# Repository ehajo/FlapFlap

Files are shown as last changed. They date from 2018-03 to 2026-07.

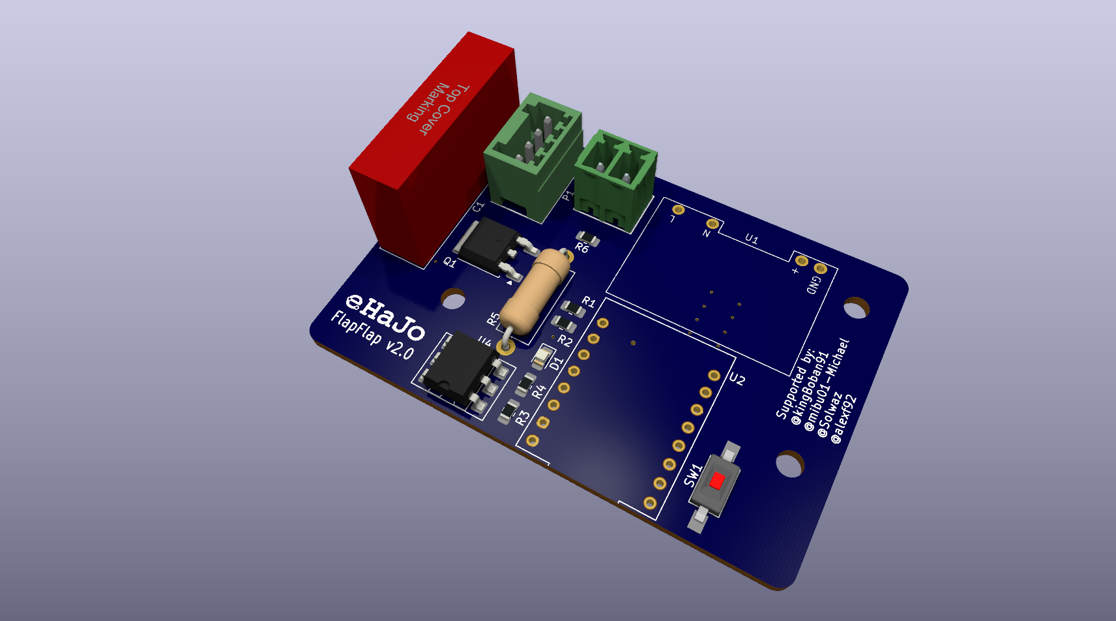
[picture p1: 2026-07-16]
Platine/KiCad/flapflap/flapflap.png

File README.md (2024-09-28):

# FlapFlap

Die Daten zum Fallblattanzeigen-Projekt, das wir auf Youtube und im Twitch-Livestream bearbeiten.

Unsere Streams findest du auf https://www.twitch.tv/ehajo

Die neue Version bekommt eine komplett neue Hardware. Es wird sowohl die komplette Ansteuerung als auch die Absolutpositionsabfrage getauscht!

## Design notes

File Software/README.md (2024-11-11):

# FlapFlap Sub-Clock & Uhr Software

Willkommen zu der FlapFlap-Software! Dieses Projekt umfasst zwei Hauptfunktionen: eine **normale Uhr** und eine **Sub-Clock**. Die Software läuft auf einem **Raspberry Pi Pico W** und verwendet den **TLV493D Magnetfeldsensor**, um die Zeit in verschiedenen Formaten zu messen und darzustellen. Sie kann für die Anzeige von Sekunden, Minuten und Stunden konfiguriert werden. Diese README erklärt die Funktionsweise, wie du die Software einrichtest und wie du die Konfiguration anpassen kannst.

## Funktionen

Die FlapFlap Software bietet eine Vielzahl von Funktionen, die auf den folgenden beiden Hauptvarianten basieren:

### 1. Normale Uhr

Die normale Uhr liest den Magnetfeldsensor aus, um den Rotationswinkel der Uhr zu berechnen. Der Mikrocontroller zeigt basierend auf diesem Winkel und der konfigurierten Logik die Zeit in **Sekunden**, **Minuten** oder **Stunden** an. Die aktuelle Uhrzeit wird per NTP-Protokoll bei funktionierendem WLAN geladen, ansonsten über einen RTC-Chip, der per I²C angeschlossen ist.

- **Sekunden**: Zeigt die Sekunden an.
- **Minuten**: Zeigt die Minuten an.
- **Stunden**: Zeigt die Stunden an.

### 2. Sub-Clock

Die Sub-Clock ist eine alternative Anzeige, die speziell für eine reduzierte Zeitdarstellung gedacht ist. Sie empfängt dieselben Werte über den UART-Datenstrom, aber die Interpretation der Daten erfolgt je nach den spezifischen Anforderungen des Projekts (z. B. eine präzisere, abgestufte Anzeige).

## Systemanforderungen

- **Hardware**:
  - Raspberry Pi Pico W oder vergleichbare Mikrocontroller mit CircuitPython-Unterstützung.
  - TLV493D Magnetfeldsensor (I2C-Schnittstelle).
  - Eine UART-Schnittstelle für die serielle Kommunikation.
- **Software**:
  - CircuitPython für die Ausführung der Software.
  - `adafruit_tlv493d`-Bibliothek für den Magnetfeldsensor.

## Installation

### Abhängigkeiten

Für die Installation sind folgende Bibliotheken erforderlich:

- **Adafruit TLV493D**: Diese Bibliothek ist notwendig, um den Magnetfeldsensor über die I2C-Schnittstelle anzusprechen.
  
Installiere die Bibliothek über den CircuitPython-Installer oder lade sie manuell herunter.

### Code Setup

1. **Code auf den Raspberry Pi Pico W hochladen**:
   Lade die Python-Dateien auf den Raspberry Pi Pico W hoch und speichere sie im Hauptverzeichnis.
   
2. **I2C und UART konfigurieren**:
   Stelle sicher, dass die I2C- und UART-Verbindungen für deinen Raspberry Pi Pico W richtig eingerichtet sind.

3. **Konfigurationsdatei (`config.json`) erstellen**:
   Stelle sicher, dass eine gültige `config.json`-Datei im Hauptverzeichnis des Dateisystems des Raspberry Pi Pico W vorhanden ist. Diese Datei enthält alle Einstellungen für die Uhr und Sub-Clock.

## config.json

Die `config.json`-Datei speichert die Konfiguration für die Uhr, einschließlich des kalibrierten Nullpunkts und des Typs der angezeigten Zeit (Sekunden, Minuten, Stunden oder eine benutzerdefinierte Sub-Clock-Logik).

### Beispiel `config.json`:

```json
{
  "calibrated_zero_angle": 91.4311,
  "type": "Sekunden"
}
```

### Konfigurationsfelder:

- **`calibrated_zero_angle`**:
  - Dies ist der kalibrierte Nullpunktwinkel in Grad. Er gibt den Referenzwinkel an, ab dem die Uhr arbeitet. Dieser Wert wird durch die Kalibrierung des Magnetfeldsensors bestimmt.
  - **Wertbereich**: Ein numerischer Wert zwischen 0 und 360.
  - **Beispiel**: `91.4311`

- **`type`**:
  - Dieser Parameter bestimmt, welche Zeit angezeigt wird und wie der empfangene Datenstrom über UART interpretiert wird. Es gibt mehrere Optionen, die du je nach deinen Anforderungen wählen kannst.
  - **Mögliche Werte für `type`**:
    - `"Sekunden"`: Die Uhr zeigt die Sekunden an. Der empfangene Datenstrom steuert die Sekunden.
    - `"Minuten"`: Die Uhr zeigt die Minuten an. Der empfangene Datenstrom steuert die Minuten.
    - `"Stunden"`: Die Uhr zeigt die Stunden an. Der empfangene Datenstrom steuert die Stunden.
    - `"nix62"`: Diese Einstellung zeigt immer die Stufe 31 an, bedeutet bei einer Minutenanzeige das Leerfeld.
    - `"nix40"`: Diese Einstellung zeigt immer die Stufe 26 an, bedeutet bei einer Stundenanzeige das Leerfeld.
    - **Beispiel für Konfigurationen**:
      - **Sekundenanzeige**:
        ```json
        {
          "calibrated_zero_angle": 91.4311,
          "type": "Sekunden"
        }
        ```
      - **Minutenanzeige**:
        ```json
        {
          "calibrated_zero_angle": 120.0,
          "type": "Minuten"
        }
        ```
      - **Stundenanzeige**:
        ```json
        {
          "calibrated_zero_angle": 180.5,
          "type": "Stunden"
        }
        ```
      - **Sub-Clock-Variante (nix62)**:
        ```json
        {
          "calibrated_zero_angle": 91.4311,
          "type": "nix62"
        }
        ```
      - **Sub-Clock-Variante (nix40)**:
        ```json
        {
          "calibrated_zero_angle": 91.4311,
          "type": "nix40"
        }
        ```

## wlan.json

Die `wlan.json`-Datei speichert die Konfiguration für die WLAN-Einstellungen. Passe diese bitte an deine Zugangsdaten zu deinem Heimnetz an.
```json
{
    "wifi_ssid": "your-ssid",
    "wifi_password": "1234567890"
}
```

## Kalibrierung

Die Kalibrierung des Magnetfeldsensors erfolgt durch den Benutzer, um den Nullpunktwinkel festzulegen. Wenn du den Button (GPIO22) drückst, wird der Sensor neu kalibriert, und der aktuelle Winkel wird als Nullpunkt gespeichert. Der Nullpunkt wird dann in der `config.json`-Datei gespeichert, sodass er bei jedem Neustart des Geräts wieder verwendet werden kann.

### Kalibrierungsschritte:

1. Drücke den Kalibrierungs-Button (GPIO22).
2. Die Software misst das Magnetfeld und berechnet den Nullpunktwinkel.
3. Der neue Nullpunkt wird in der `config.json` gespeichert.

## UART-Datenstrom

Die Software empfängt über die serielle Schnittstelle UART bis zu drei Bytes:

1. **Sekunden (Typ `"Sekunden"`)**: Das erste Byte gibt die Zielstufe für die Sekunden an (Wertbereich: 0-62).
2. **Minuten (Typ `"Minuten"`)**: Das zweite Byte gibt die Zielstufe für die Minuten an (Wertbereich: 0-62).
3. **Stunden (Typ `"Stunden"`)**: Das dritte Byte gibt die Zielstufe für die Stunden an (Wertbereich: 0-40).

Die empfangenen Bytes werden verwendet, um die `step_target`-Variable zu setzen. Wenn die aktuelle Stufe der Zielstufe entspricht, wird die Anzeige entsprechend aktualisiert.

### Beispiel für einen gültigen Datenstrom:
- Wenn der `type` auf `"Sekunden"` gesetzt ist, wird das erste Byte die Sekunden definieren.
- Bei `"Minuten"` und `"Stunden"` werden die entsprechenden Bytes verwendet.

## Häufige Fehlerbehebung

- **Konfigurationsdatei fehlt**: Wenn die `config.json`-Datei nicht gefunden wird, wird ein Standardwert verwendet. Stelle sicher, dass die Datei korrekt erstellt und im richtigen Verzeichnis abgelegt wurde.
- **Datenübertragung funktioniert nicht**: Überprüfe die UART-Verbindung und stelle sicher, dass der Mikrocontroller korrekt mit dem Sender kommuniziert.
- **Magnetfeldsensor kalibrieren**: Falls die Kalibrierung fehlschlägt oder der Nullpunkt fehlerhaft ist, stelle sicher, dass der Magnetfeldsensor richtig angeschlossen und korrekt kalibriert wurde.

## Lizenz

Dieses Projekt ist unter der [MIT-Lizenz](LICENSE) lizenziert.

---

Für weitere Informationen oder Fragen besuche unsere Website: [eHaJo.de](https://www.eHaJo.de) oder schließe dich unserem [Twitch-Livestream](https://www.twitch.tv/eHaJo) an!

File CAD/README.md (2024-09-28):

# CAD-Daten FlapFlap

Die Daten wurden mit AlibreDesign erstellt. Zusätzlich findest du hier Step-Daten zum Import in andere CAD-Programme!

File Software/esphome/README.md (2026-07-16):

# FlapFlap

ESPHome-Projekt für eine historische Fallblattanzeige mit Magnetfeldsensor-Rückmeldung und pulseweiser Motoransteuerung.

## Ziel des Projekts

Dieses Projekt steuert eine Fallblattanzeige mit einem ESP32-C3 Super Mini.  
Die Blattposition wird über einen **TLV493D 3D-Magnetfeldsensor** erfasst.  
Der Motor wird über einen **MOC3043** angesteuert.  
Die Anzeige bewegt sich **nur vorwärts**.  
Ziel ist eine robuste Anfahrt eines gewünschten Blatts mit Rückmeldung über den Sensor.

## Hardware

### Controller
- ESP32-C3 Super Mini

### Sensor
- Infineon TLV493D-A1B6
- I2C-Adresse: `0x5E`

### Aktorik
- MOC3043 zur Ansteuerung des Motors

### Bedienelement
- Taster gegen GND, interner Pull-up im ESP32-C3

## Verbindliche Pinbelegung

- **TLV493D SDA** → `GPIO0`
- **TLV493D SCL** → `GPIO1`
- **Taster** → `GPIO3` gegen GND
- **MOC3043 Eingang** → `GPIO10`

## Wichtige Hardware-Hinweise

### Pull-ups
Für I2C sind externe Pull-ups erforderlich:
- SDA → 3V3 über **4,7 kΩ**
- SCL → 3V3 über **4,7 kΩ**

Keine 1-kΩ-Pull-ups verwenden.

### Versorgung
- TLV493D nur mit **3,3 V**
- keine 5-V-Pegel an ESP32-C3-GPIOs

### ESP32-C3 Pin-Einschränkungen
Diese Pins möglichst nicht für das Projekt verwenden:
- `GPIO2`, `GPIO8`, `GPIO9` → Strapping-/Bootstrap-Pins
- `GPIO4` bis `GPIO7` → JTAG-belegt bzw. vermeiden
- `GPIO18`, `GPIO19` → USB Serial/JTAG
- `GPIO20`, `GPIO21` → nach Möglichkeit frei lassen

## Software-Stack

- **ESPHome 2026.3.2**
- Arduino-Framework auf ESP32-C3
- lokaler External Component für den TLV493D und die Regelung

## Repo-Struktur

```text
.
├── flapflap.yaml
├── my_components/
│   └── tlv493d_test/
│       ├── __init__.py
│       ├── tlv493d_test.h
│       └── tlv493d_test.cpp
└── README.md
```

## Aktueller Funktionsumfang

Der aktuelle Stand kann:

- TLV493D per I2C ansprechen
- Magnetfeldwerte X/Y/Z lesen
- Winkel aus X/Y berechnen
- Winkel glätten und stabilisieren
- aktuelle Blattnummer aus Winkel und Nullwinkel bestimmen
- auf ein beliebiges Blatt kalibrieren
- Motor pulseweise ansteuern
- ein Zielblatt anfahren
- Timeout und fehlenden Fortschritt erkennen

## Grundannahmen der Regelung

- Die Anzeige bewegt sich nur **vorwärts**
- Die typische Drehgeschwindigkeit liegt ungefähr bei **5 Blättern pro Sekunde**
- Die Blattnummer wird aus dem Sensorwinkel mit Hysterese bestimmt
- Die Sensorlogik muss im Stillstand stabil sein, darf aber während der Bewegung nicht zu träge werden

## Wichtige ESPHome-Parameter

Typische relevante Parameter im Component:
- `pages`
- `zero_angle`
- `calibration_leaf`
- `target_leaf`
- `sensor_samples`
- `motor_pulse_ms`
- `motor_settle_ms`
- `move_timeout_ms`
- `max_pulses_per_move`
- `unchanged_limit`

## Build

Projekt kompilieren:

```bash
esphome compile flapflap.yaml
```

Projekt flashen / ausführen:

```bash
esphome run flapflap.yaml
```

Logs ansehen:

```bash
esphome logs flapflap.yaml
```

## Typischer Testablauf

1. Hardware prüfen
2. I2C-Scan prüfen, Sensor muss auf `0x5E` erscheinen
3. Sensorwerte X/Y/Z und Winkel prüfen
4. Kalibrierblatt setzen
5. `Hier kalibrieren` auslösen
6. prüfen, ob `Aktuelles Blatt` stabil ist
7. `Zielblatt` setzen
8. `Zu Zielblatt fahren` testen
9. bei Problemen Logs auf Blattwechsel, Pulse und Status prüfen

## Bekannte Besonderheiten

- Der TLV493D kann nach problematischen I2C-Transaktionen in einem ungünstigen Zustand hängen. In solchen Fällen hilft oft ein vollständiger Power-Cycle.
- Blattgrenzen sind empfindlich; deshalb sind Mittelung, Vektorfilterung und Hysterese wichtig.
- Übergänge um 0°/360° müssen besonders robust behandelt werden.

## Erwartungen an Änderungen

Bitte Änderungen **minimal und gezielt** halten.

### Nicht ohne Not ändern
- Pinbelegung
- I2C-Adresse
- Kalibrierlogik-Grundprinzip
- Blattberechnung nur vorwärts
- ESPHome-Version-Kompatibilität zu 2026.3.2

### Bevorzugte Arbeitsweise
- kleine, nachvollziehbare Änderungen
- bestehende Logik erhalten
- zuerst Buildfehler beheben
- danach Kompilierung erneut prüfen
- keine unnötigen Refactorings

## Definition of Done

Eine Änderung ist fertig, wenn:

1. `esphome compile flapflap.yaml` erfolgreich läuft
2. keine bestehenden Funktionen unbeabsichtigt entfernt wurden
3. Sensorwerte weiterhin plausibel sind
4. Kalibrierung weiterhin funktioniert
5. die Blattberechnung stabil bleibt
6. Motorsteuerung nicht dauerhaft hängen bleibt
7. Logs weiterhin hilfreich und präzise sind

## Hinweise für Coding Agents / Codex

Wenn du als Agent in diesem Repo arbeitest:

- lies zuerst diese Datei vollständig
- ändere nur die minimal nötigen Dateien
- erkläre kurz die Ursache eines Problems
- führe nach Änderungen `esphome compile flapflap.yaml` aus
- behebe verbleibende Buildfehler
- erhalte bestehende Hardware-Pins und Projektziele
- vermeide große Umbauten ohne ausdrückliche Aufforderung
- bevorzuge robuste, konservative Änderungen gegenüber kreativen Refactorings

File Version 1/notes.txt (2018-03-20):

52,08uS pro Bit @ 19k2

T3.5 = 156,25 uS @ 19K2

@8MHz 156,2uS ist x Clk

156,2 uS / 125ns = 156,2 / 125 * 1000

= 1249,6 Clocks

-> 16 Bit Timer mit F_CPU nötig, oder 8 Bit Timer mit F_CPU /4 bis F_CPU / 8

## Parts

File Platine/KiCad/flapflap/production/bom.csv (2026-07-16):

Designator | Footprint | Quantity | Value | LCSC Part #
C1 | C_Wurth_WCAP-FTBP-P22.5L26W7H16.5 | 1 | 1.5 uF
C2 | 0805 | 1 | 100n
D1 | 0805 | 1 | LED
P1 | 691382000004 | 1 | 691382010004
P2 | 691321300002 | 1 | 691322110002
Q1 | TO-252-2 | 1 | T835-600B-TR
R1, R2 | 0805 | 2 | 4k7
R3, R4 | 0805 | 2 | 470R
R5 | R_Axial_DIN0414_L11.9mm_D4.5mm_P15.24mm_Horizontal | 1 | 3k3/2W
R6 | 0805 | 1 | 1k
SW1 | SW_SPST_FSMSM | 1 | SW_Push
U1 | ACDC-230 | 1 | youmile_230acdc
U2 | MODULE_ESP32-C3_SUPERMINI_TH | 1 | ESP32-C3_SUPERMINI_TH
U3 | SOT-23-6 | 1 | TLV493D
U4 | DIP-6_W7.62mm_SMDSocket_SmallPads | 1 | MOC3043M

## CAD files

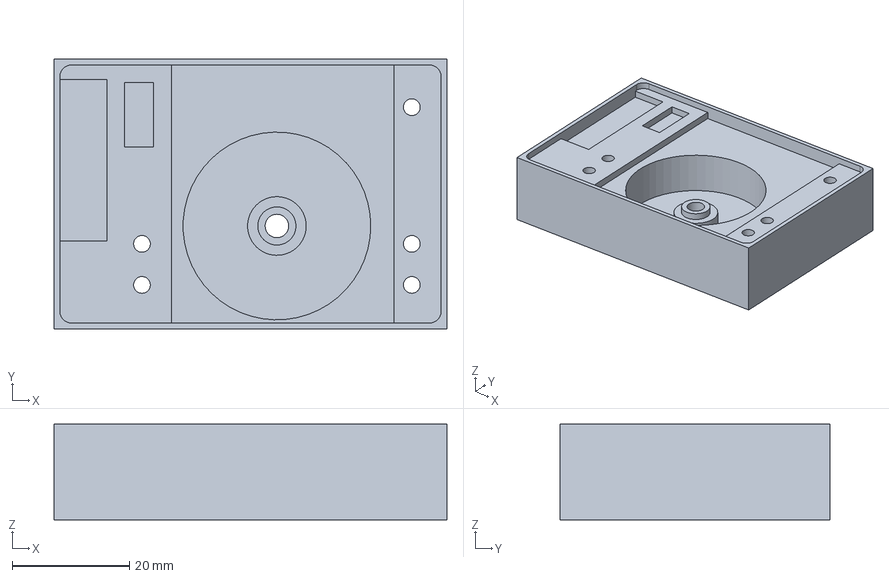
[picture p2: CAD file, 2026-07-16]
CAD/gehäuse_neu.stp
67.0 x 46.0 x 16.3 mm

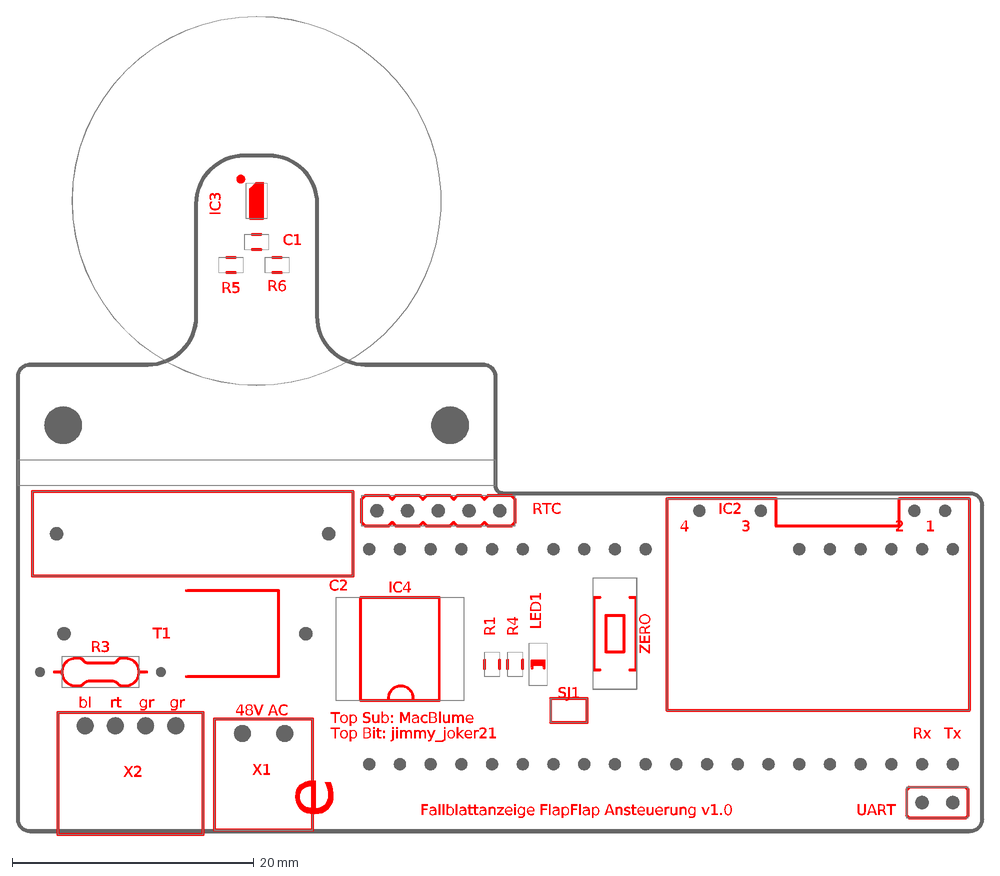
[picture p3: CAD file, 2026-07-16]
Platine/flapflap_rPi_picoW.dxf
Rx
Tx
Top Bit: jimmy_joker21
Top Sub: MacBlume
e
Fallblattanzeige FlapFlap Ansteuerung v1.0
gr
rt
bl
48V AC
R6
R5
SJ1
C2
ZERO
UART
R4
LED1
RTC
X2
R3
T1
R1
IC4
C1
IC3
IC2
4
3
2
1
X1

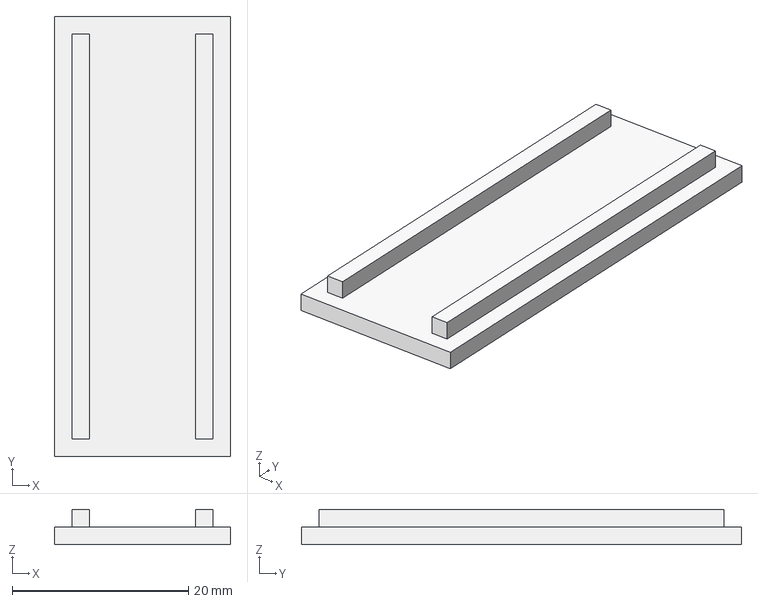
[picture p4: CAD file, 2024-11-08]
CAD/stromversorgung_deckel.stp
20.0 x 50.0 x 4.00 mm

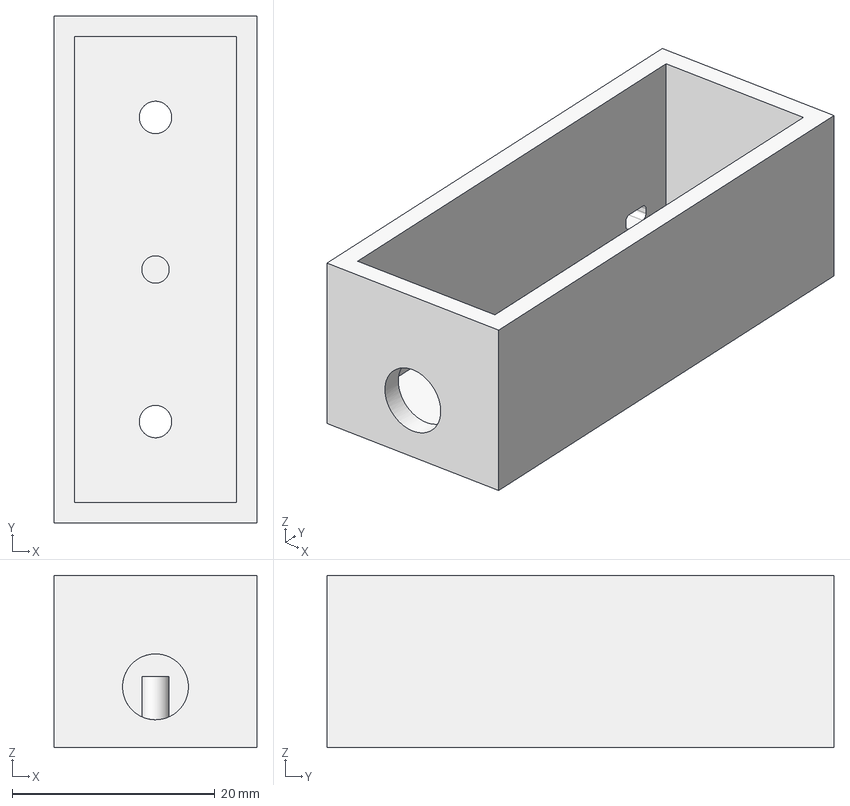
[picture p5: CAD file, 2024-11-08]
CAD/stromversorgung_unterteil.stp
20.0 x 50.0 x 17.0 mm

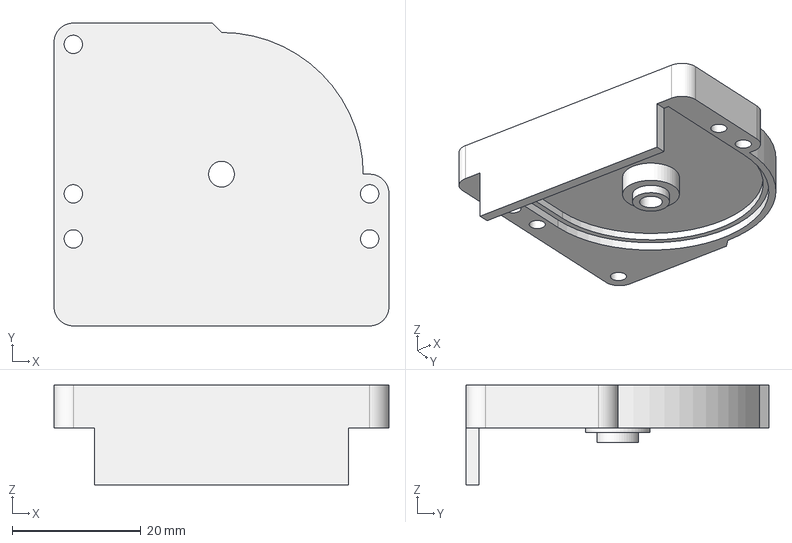
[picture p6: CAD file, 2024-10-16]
CAD/inkrementalgeber_unterseite.stp
52.0 x 47.0 x 15.5 mm

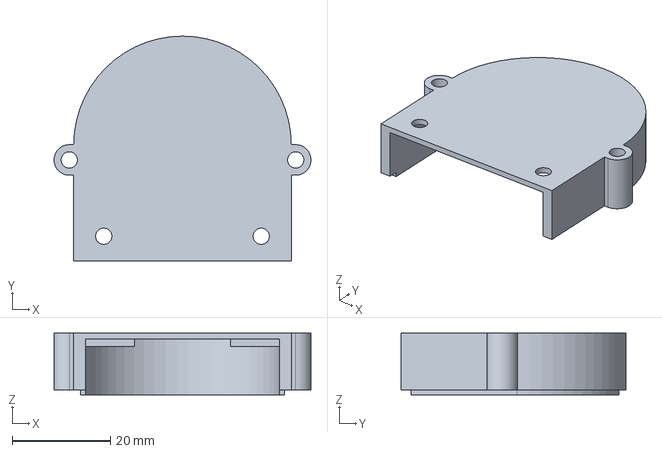
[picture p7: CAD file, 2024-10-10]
CAD/inkrementalgeber_oberseite.stp
52.2 x 45.7 x 12.5 mm

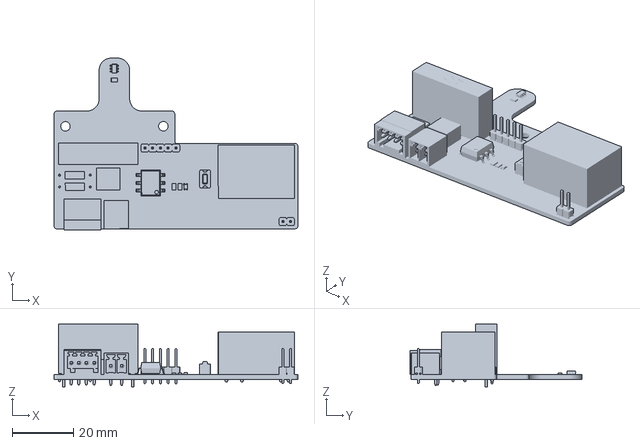
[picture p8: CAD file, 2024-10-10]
CAD/flapflap_rpi_picow.3mf
79.8 x 56.2 x 20.5 mm

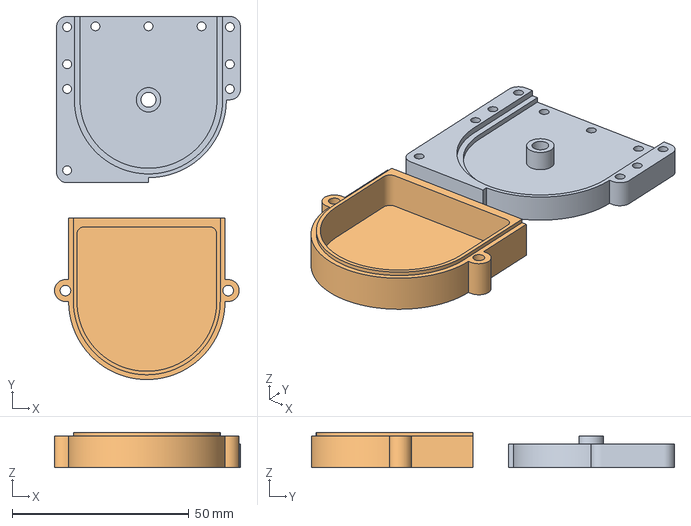
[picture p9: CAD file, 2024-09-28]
CAD/inkrementalgeber_gehaeuse.3mf
52.6 x 102.6 x 10.0 mm
inkrementalgeber_unterseite.stp
inkrementalgeber_oberseite.stp

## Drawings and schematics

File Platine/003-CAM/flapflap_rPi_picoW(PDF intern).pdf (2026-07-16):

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

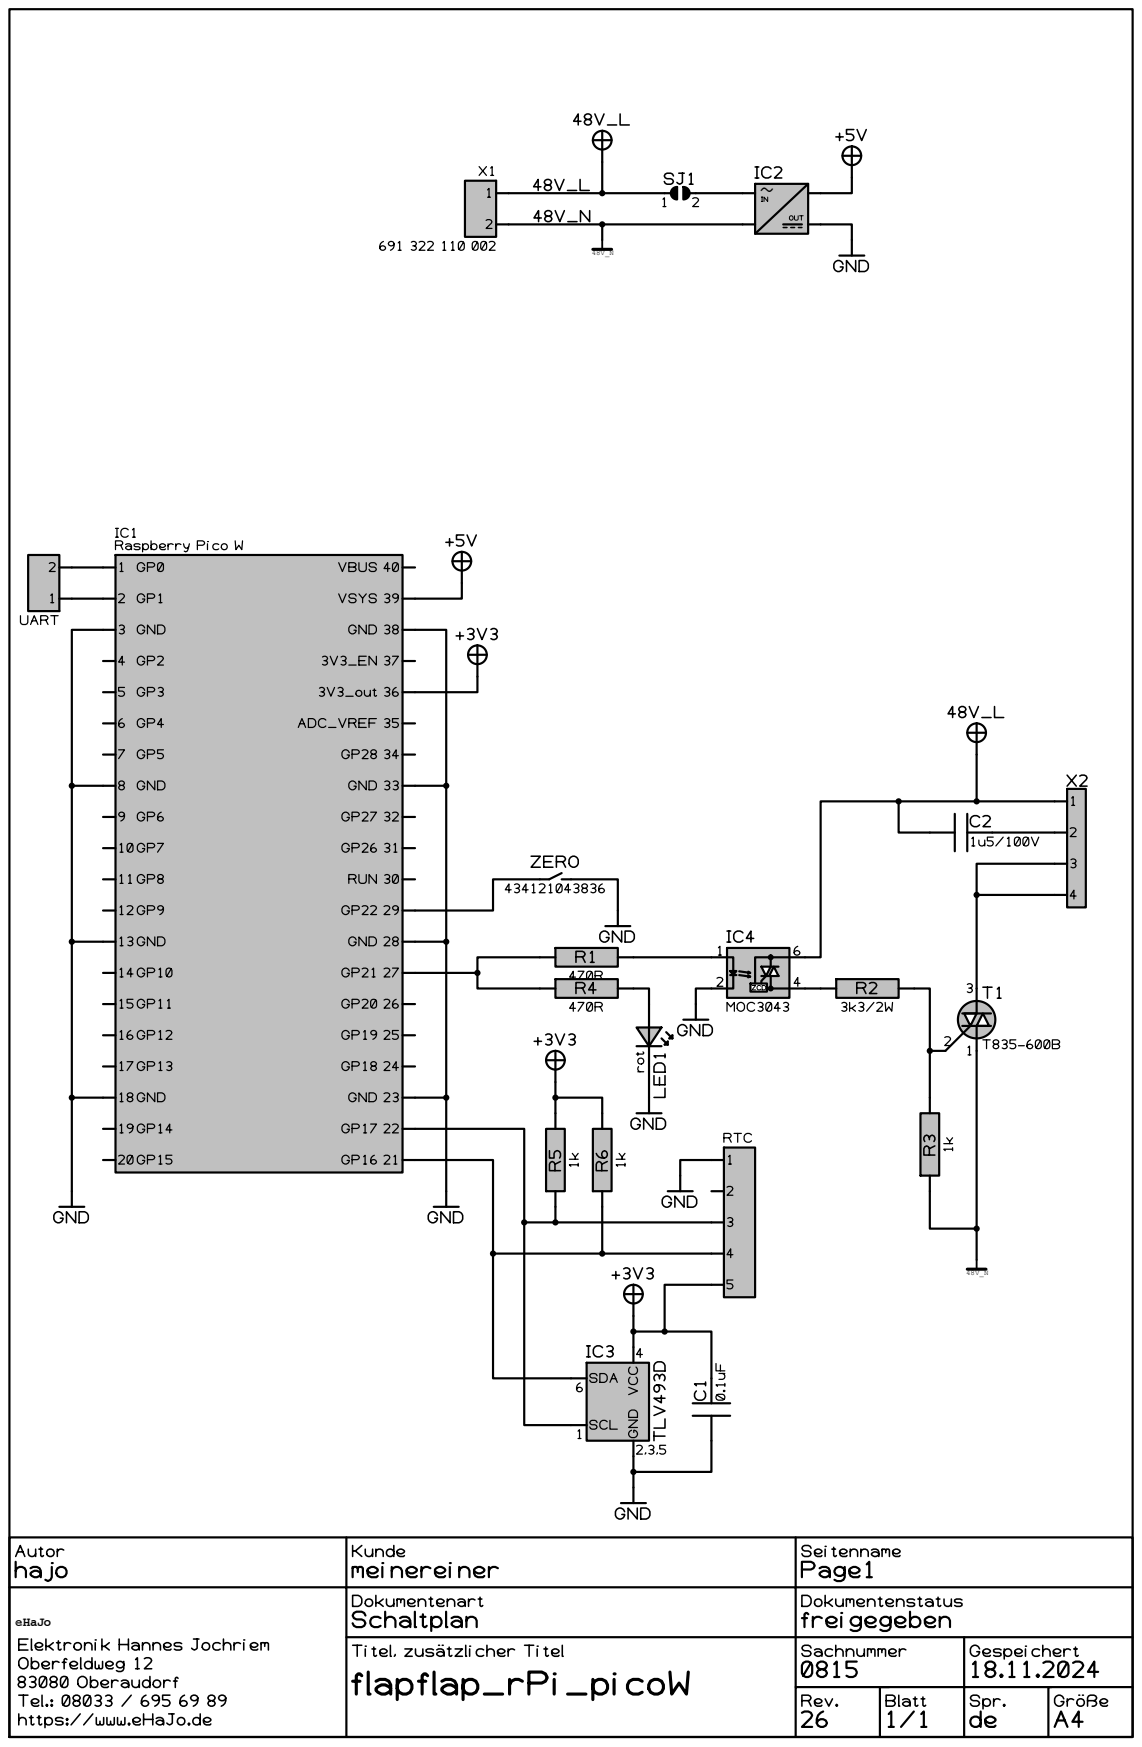
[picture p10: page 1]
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

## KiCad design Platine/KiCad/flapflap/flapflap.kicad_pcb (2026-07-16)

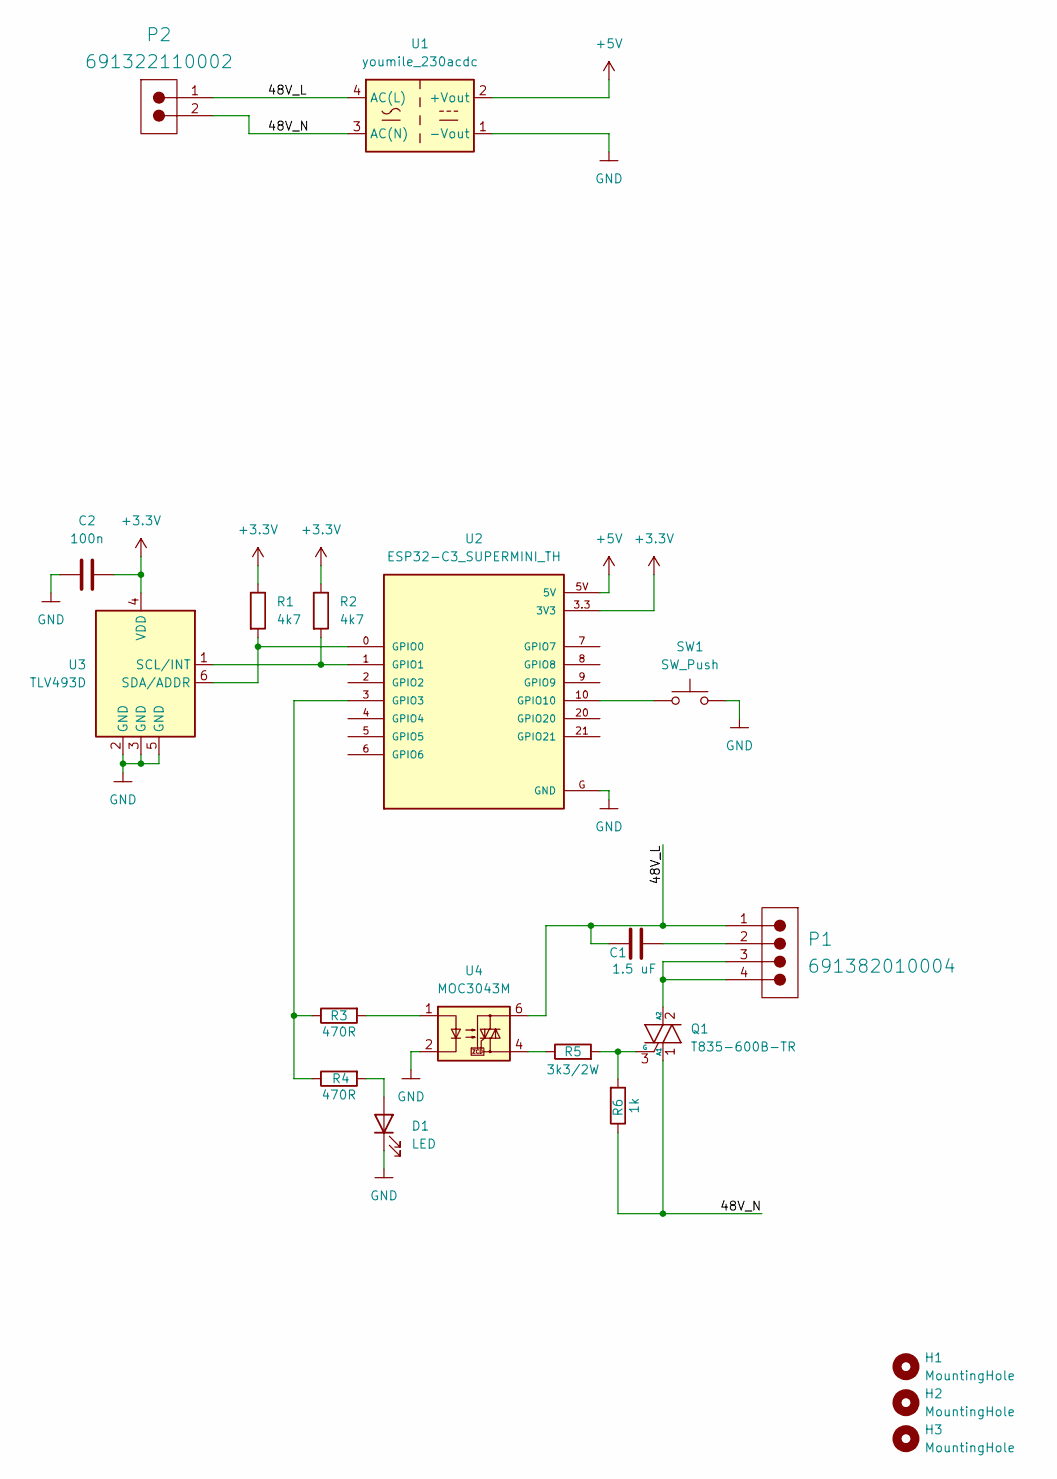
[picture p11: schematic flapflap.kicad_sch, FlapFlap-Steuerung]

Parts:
C1: 1.5 uF; C_Wurth_WCAP-FTBP-P22.5L26W7H16.5; Voltage 250; Part Number 890273326007CS
C2: 100n; C_0805_2012Metric_Pad1.18x1.45mm_HandSolder
D1: LED; LED_0805_2012Metric_Pad1.15x1.40mm_HandSolder
H1, H2, H3: MountingHole; MountingHole_3.2mm_M3
P1: 691382010004; 691382000004; Working Voltage 300V; Manufacturer Part Number 691382000004
P2: 691322110002; 691321300002; Working Voltage 300V; Manufacturer Part Number 691321300002
Q1: T835-600B-TR; TO-252-2
R1, R2: 4k7; R_0805_2012Metric_Pad1.20x1.40mm_HandSolder
R3, R4: 470R; R_0805_2012Metric_Pad1.20x1.40mm_HandSolder
R5: 3k3/2W; R_Axial_DIN0414_L11.9mm_D4.5mm_P15.24mm_Horizontal
R6: 1k; R_0805_2012Metric_Pad1.20x1.40mm_HandSolder
SW1: SW_Push; SW_SPST_FSMSM
U1: youmile_230acdc; ACDC-230
U2: ESP32-C3_SUPERMINI_TH; MODULE_ESP32-C3_SUPERMINI_TH
U3: TLV493D; SOT-23-6
U4: MOC3043M; DIP-6_W7.62mm_SMDSocket_SmallPads

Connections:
+3.3V: C2.2, R1.1, R2.1, U2.3.3 (3V3), U3.4 (VDD)
+5V: U1.2 (+Vout), U2.5V
/48V_L: C1.1, P1.1, P2.1, U1.4 (AC(L)), U4.6
/48V_N: P2.2, Q1.1 (A1), R6.1, U1.3 (AC(N))
GND: C2.1, D1.1 (K), SW1.1, U1.1 (-Vout), U2.G (GND), U3.2 (GND), U3.3 (GND), U3.5 (GND), U4.2
unnamed: C1.2, P1.2
unnamed: D1.2 (A), R4.2
unnamed: P1.3, P1.4, Q1.2 (A2)
unnamed: Q1.3 (G), R5.2, R6.2
unnamed: R3.2, U4.1
unnamed: R5.1, U4.4
unnamed: R1.2, U2.0 (GPIO0), U3.6 (SDA/ADDR)
unnamed: R2.2, U2.1 (GPIO1), U3.1 (SCL/INT)
unnamed: R3.1, R4.1, U2.3 (GPIO3)
unnamed: SW1.2, U2.10 (GPIO10)

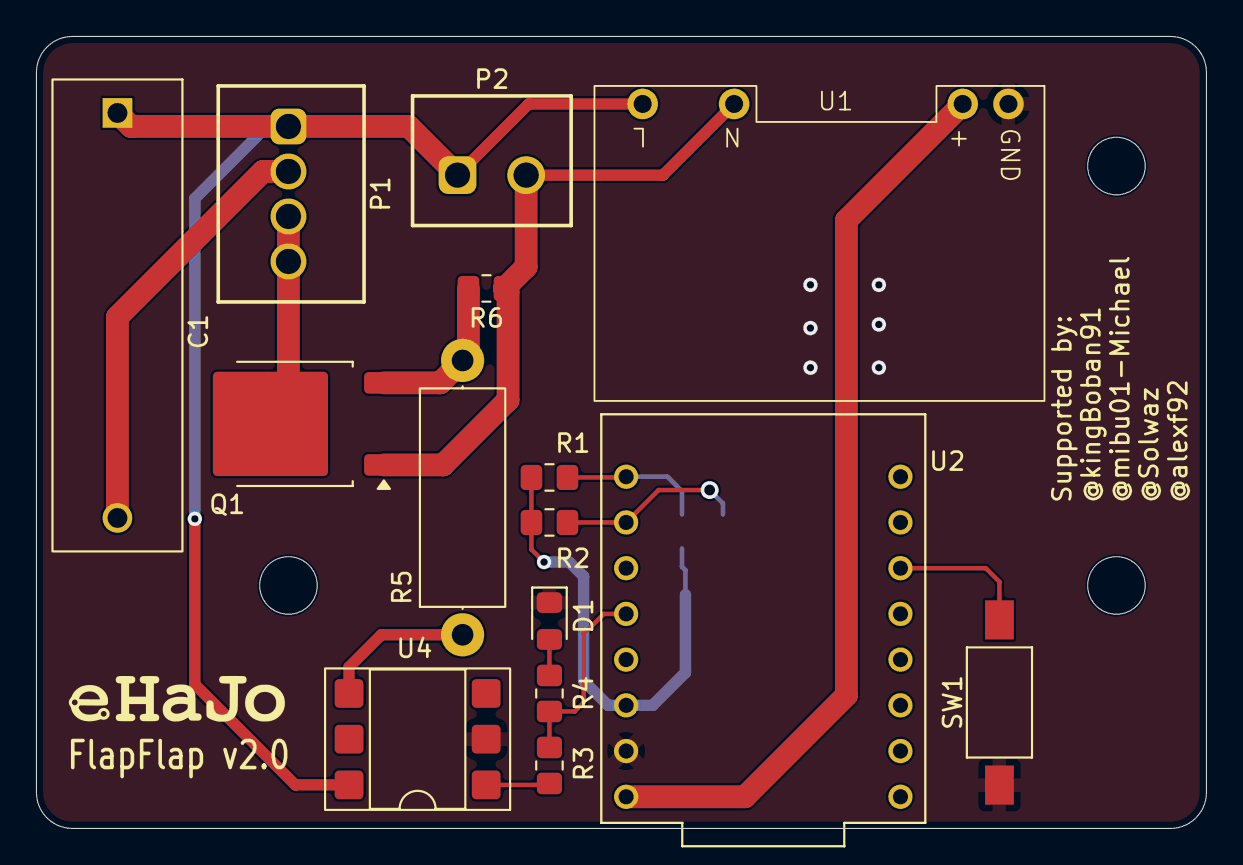
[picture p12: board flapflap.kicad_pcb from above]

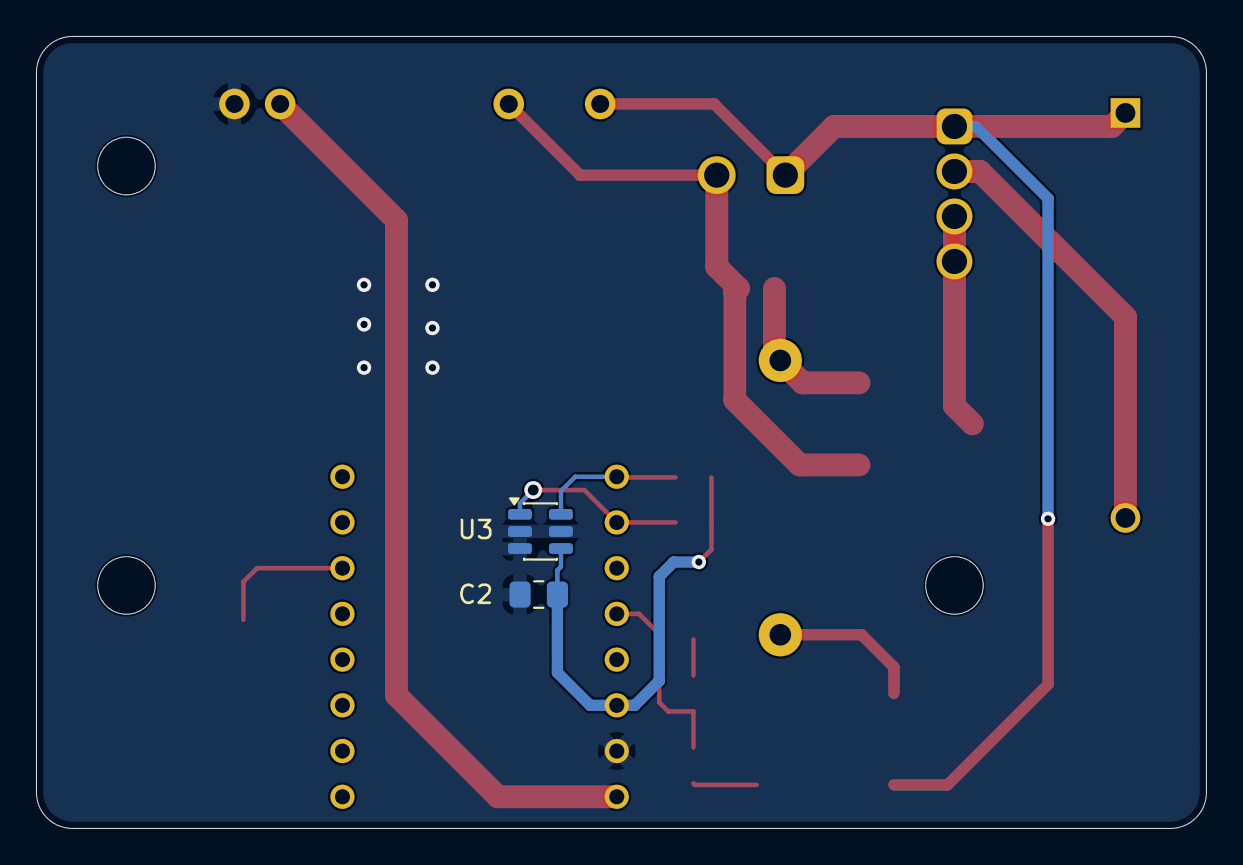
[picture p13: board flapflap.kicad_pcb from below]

Board: 2 copper layers, 65.0 x 44.0 mm, 20 parts (2 on the bottom side), 15 nets.

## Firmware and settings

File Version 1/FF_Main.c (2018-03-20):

/******************************************************************************
 * @file     EasyMain.c
 * @brief    Uses a system timer to toggle the  ports P0.5, P0.6, P1.5 and P1.6 with 200ms frequency.
 *			 LEDs that are connected to these ports will toggle respectively.
 * 			 In addition it uses the UART of USIC Channel 1 to send a message every 2s to a terminal
 *			 emulator. The communication settings are 57.6kbps/8N1
 *			 P1.3 is configured as input (RXD) and P1.2 is configured as output(TXD)
 *			 This project runs without modifications on the XMC1100 kit for ARDUINO
 * @version  V1.0
 * @date     20. February 2015
 * @note
 * Copyright (C) 2015 Infineon Technologies AG. All rights reserved.
 ******************************************************************************
 * @par
 * Infineon Technologies AG (Infineon) is supplying this software for use with
 * Infineon�s microcontrollers.
 * This file can be freely distributed within development tools that are
 * supporting such microcontrollers.
 * @par
 * THIS SOFTWARE IS PROVIDED "AS IS".  NO WARRANTIES, WHETHER EXPRESS, IMPLIED
 * OR STATUTORY, INCLUDING, BUT NOT LIMITED TO, IMPLIED WARRANTIES OF
 * MERCHANTABILITY AND FITNESS FOR A PARTICULAR PURPOSE APPLY TO THIS SOFTWARE.
 * INFINEON SHALL NOT, IN ANY CIRCUMSTANCES, BE LIABLE FOR SPECIAL, INCIDENTAL,
 * OR CONSEQUENTIAL DAMAGES, FOR ANY REASON WHATSOEVER.
 *****************************************************************************/

#include <string.h>

#include "XMC1100.h"
#include "xmc_uart.h"
#include "xmc_gpio.h"
#include "xmc_ccu4.h"
#include "xmc_scu.h"

#include "GPIO.h"

#include "port.h"
#include "mbport.h"
#include "mb.h"

#include "modbus_if.h"

#define  DSEL_DXnA ( 0 )
#define  DSEL_DXnB ( 1 )
#define  DSEL_DXnC ( 2 )
#define  DSEL_DXnD ( 3 )
#define  DSEL_DXnE ( 4 )
#define  DSEL_DXnF ( 5 )
#define  DSEL_DXnG ( 6 )
#define  DSEL_ALWAYS_ONE ( 7 )

/*********************************************************************************************************************
 * MACROS
 *********************************************************************************************************************/
#define SLICE_PTR         CCU40_CC40
#define MODULE_PTR        CCU40
#define MODULE_NUMBER     (0U)
#define SLICE_NUMBER      (0U)
#define CCU_OUTPUT		  P0_5
/* We need 3.5T as 3.5 Char Time */
/* We use 19200 Baud meaning 52us per Bit */
/* With 8e1 and 1 stopbit and 1 startbit we got 11 Bits per char */
/* times 3.5 menas 38.5 bits -> 38.5*50us = 2.028 ms timeout.... */

/* Period 62499 -> 64000000 means (64Mhz/1024 -1) resulting in 1 secong */
/* We need a 2.028ms timer here with 1 tick = 16us */
/* Resulting in 127,75 -> 128 ticks -1 - > 127 */


#define PWMPERIOD		  (127U) //PWM period calculated based on PCLK = 64MHz
#define DUTYCYCLE		  (127U)



XMC_GPIO_CONFIG_t rx_pin_config;
XMC_GPIO_CONFIG_t tx_pin_config;


/* Config for Systick timer */
#define TICKS_PER_SECOND 1000

XMC_CCU4_SLICE_COMPARE_CONFIG_t compare_config =
{
  .timer_mode 		   = (uint32_t) XMC_CCU4_SLICE_TIMER_COUNT_MODE_EA,
  .monoshot   		   = (uint32_t) true,
  .shadow_xfer_clear   = (uint32_t) 0,
  .dither_timer_period = (uint32_t) 0,
  .dither_duty_cycle   = (uint32_t) 0,
  .prescaler_mode	   = (uint32_t) XMC_CCU4_SLICE_PRESCALER_MODE_NORMAL,
  .mcm_enable		   = (uint32_t) 0,
  .prescaler_initval   = (uint32_t) 10,
  .float_limit		   = (uint32_t) 0,
  .dither_limit		   = (uint32_t) 0,
  .passive_level 	   = (uint32_t) XMC_CCU4_SLICE_OUTPUT_PASSIVE_LEVEL_LOW,
  .timer_concatenation = (uint32_t) 0
};

volatile bool boService=true;
extern void ff_check_position( void );

volatile uint32_t Delay_x =0;
void SysTick_Handler(void)
{
	if(Delay_x>0){
		Delay_x--;
	}
	if(boService==false){
		ff_check_position();
	}


}


void SetUpGPIO(){

	/* ID Switch */
	/*
	 * P2.4
	 * P2.5
	 * P2.6
	 * P2.7
	 * P2.8
	 * P2.9
	 * P2.10
	 * P2.11
	 *
	 */

	XMC_GPIO_CONFIG_t pin_input_config_pullup =
		{
		   .mode                = XMC_GPIO_MODE_INPUT_PULL_UP,
		   .input_hysteresis    = XMC_GPIO_INPUT_HYSTERESIS_STANDARD,
		   .output_level        = XMC_GPIO_OUTPUT_LEVEL_LOW,
		};
	XMC_GPIO_Init(P2_4, &pin_input_config_pullup);
	XMC_GPIO_Init(P2_5, &pin_input_config_pullup);
	XMC_GPIO_Init(P2_6, &pin_input_config_pullup);
	XMC_GPIO_Init(P2_7, &pin_input_config_pullup);
	XMC_GPIO_Init(P2_8, &pin_input_config_pullup);
	XMC_GPIO_Init(P2_9, &pin_input_config_pullup);
	XMC_GPIO_Init(P2_10, &pin_input_config_pullup);
	XMC_GPIO_Init(P2_11, &pin_input_config_pullup);

	XMC_GPIO_CONFIG_t pin_output_config_push_pull =
			{
			   .mode                = XMC_GPIO_MODE_OUTPUT_PUSH_PULL,
			   .input_hysteresis    = XMC_GPIO_INPUT_HYSTERESIS_STANDARD,
			   .output_level        = XMC_GPIO_OUTPUT_LEVEL_HIGH,
			};

	/* Output for Waveform Generation Flap Flap */
	XMC_GPIO_Init(P0_13, &pin_output_config_push_pull); /* !AD    */
	XMC_GPIO_Init(P0_1, &pin_output_config_push_pull); /* !COL    */
	XMC_GPIO_Init(P0_2, &pin_output_config_push_pull); /* !Start    */

	/* LEDs */
   XMC_GPIO_Init(XMC_GPIO_PORT0,4, &pin_output_config_push_pull);
   XMC_GPIO_Init(XMC_GPIO_PORT0,3, &pin_output_config_push_pull);


	/* Encoder Input */
	XMC_GPIO_CONFIG_t pin_input_config_inv_pullup =
		{
		   .mode                = XMC_GPIO_MODE_INPUT_INVERTED_PULL_UP,
		   .input_hysteresis    = XMC_GPIO_INPUT_HYSTERESIS_STANDARD,
		   .output_level        = XMC_GPIO_OUTPUT_LEVEL_LOW,
		};

	XMC_GPIO_Init(P1_0, &pin_input_config_inv_pullup);
	XMC_GPIO_Init(P1_1, &pin_input_config_inv_pullup);
	XMC_GPIO_Init(P1_2, &pin_input_config_inv_pullup);
	XMC_GPIO_Init(P1_3, &pin_input_config_inv_pullup);
	XMC_GPIO_Init(P1_4, &pin_input_config_inv_pullup);
	XMC_GPIO_Init(P1_5, &pin_input_config_inv_pullup);


	/* TX Init */
	XMC_GPIO_Init(P2_2, &pin_output_config_push_pull);



	/* Disable Drive */
	XMC_GPIO_SetOutputHigh(P0_13);
	XMC_GPIO_SetOutputHigh(P0_1);
	XMC_GPIO_SetOutputHigh(P0_2);

	/* Disable TX  */
	XMC_GPIO_SetOutputLow(P0_3);
	XMC_GPIO_SetOutputHigh(P0_4);

	ff_setup();
}

const XMC_SCU_CLOCK_CONFIG_t clock_config =
{
  .pclk_src = XMC_SCU_CLOCK_PCLKSRC_DOUBLE_MCLK, /*PCLK = 2*MCLK*/
  .rtc_src = XMC_SCU_CLOCK_RTCCLKSRC_DCO2,
  .fdiv = 0,  /**< Fractional divider */
  .idiv = 1,  /**MCLK = 32MHz */
};

unsigned char ReverseBits(uint8_t v)
{
    v = ((v >> 1) & 0x55) | ((v & 0x55) << 1);
    v = ((v >> 2) & 0x33) | ((v & 0x33) << 2);
    v = ((v >> 4) & 0x0F) | ((v & 0x0F) << 4);
    return v;
}

uint8_t ReadDipSwitch( void ){

uint8_t Value = ((PORT2->IN & 0x00000FF0)>>4);
/* Change bits as someone may need to read more */
Value=ReverseBits(Value);
Value=~Value;
return Value;

}

void __delay_ms(uint32_t d){

	while(Delay_x!=d){
		  Delay_x=d;
	  }

	  while(Delay_x>0){
		  __NOP();
	  }

}
volatile uint8_t u8Address=0;
int main(void)
{
	uint32_t Delay = 0xFFFF;
	uint8_t u8DIPSwitch=0;
	/* Ensure clock frequency is set at 64MHz (MCLK) */
	XMC_SCU_CLOCK_Init(&clock_config);

	/* Ensure fCCU reaches CCU40 */
		XMC_CCU4_SetModuleClock(MODULE_PTR, XMC_CCU4_CLOCK_SCU);
		XMC_CCU4_Init(MODULE_PTR, XMC_CCU4_SLICE_MCMS_ACTION_TRANSFER_PR_CR);

		/* Get the slice out of idle mode */
		XMC_CCU4_EnableClock(MODULE_PTR, SLICE_NUMBER);

		/* Start the prescaler and restore clocks to slices */
		XMC_CCU4_StartPrescaler(MODULE_PTR);

		/* Initialize the Slice */
		XMC_CCU4_SLICE_CompareInit(SLICE_PTR, &compare_config);

		/* Enable compare match events */
		XMC_CCU4_SLICE_EnableEvent(SLICE_PTR, XMC_CCU4_SLICE_IRQ_ID_COMPARE_MATCH_UP);

	    /* Connect compare match event to SR0 */
		XMC_CCU4_SLICE_SetInterruptNode(SLICE_PTR, XMC_CCU4_SLICE_IRQ_ID_COMPARE_MATCH_UP, XMC_CCU4_SLICE_SR_ID_0);

		/* Configure NVIC */
		/* Set priority */
		NVIC_SetPriority(CCU40_0_IRQn, 3U);

		/* Enable IRQ */
		NVIC_EnableIRQ(CCU40_0_IRQn);

		/* Program duty cycle = 50% at 1Hz frequency */
		XMC_CCU4_SLICE_SetTimerCompareMatch(SLICE_PTR, DUTYCYCLE);
		XMC_CCU4_SLICE_SetTimerPeriodMatch(SLICE_PTR, PWMPERIOD);

		/* Enable shadow transfer */
		XMC_CCU4_EnableShadowTransfer(MODULE_PTR, (uint32_t)(XMC_CCU4_SHADOW_TRANSFER_SLICE_0|XMC_CCU4_SHADOW_TRANSFER_PRESCALER_SLICE_0));

		/*Enable CCU4 output*/
		/*XMC_GPIO_CONFIG_t ccu_output_config =
		{
		   .mode                = XMC_GPIO_MODE_OUTPUT_PUSH_PULL_ALT4,
		   .input_hysteresis    = XMC_GPIO_INPUT_HYSTERESIS_STANDARD,
		   .output_level        = XMC_GPIO_OUTPUT_LEVEL_LOW,
		};

		XMC_GPIO_Init(CCU_OUTPUT, &ccu_output_config);
		*/





  SetUpGPIO();


  MB_register_UART(XMC_UART0_CH0);
  SysTick_Config(SystemCoreClock / TICKS_PER_SECOND);
  /* Address of 0 disabels the device */
  __delay_ms(250);
  do{
	  u8DIPSwitch = ReadDipSwitch();
  }
  while(0==(u8DIPSwitch&0x3F));
  if(0!=(u8DIPSwitch&0x80)){
	  /* We enter the Testmode Position will be set by DIP Switch */

	  /* If bit 6 is used we just set the pins to dsiplay the address */
	  if(u8DIPSwitch&0x40){
		  voService(); /* Set the IO's */
		  while(1==1){
		  __NOP(); /* We do nothing */
		  }
	  } else{ /* Okay we now will use the DIP ones for position */
		  boService=false;
		  while(1==1){
			  /* We Read the Dipswitch and Write the Position */
			  u8DIPSwitch = ReadDipSwitch();
			  voManualSetPosition((u8DIPSwitch&0x3F));
		  }
	  }


  } else {
	  /* We enter normal operation */
	  boService=false;
	  u8Address = u8DIPSwitch&0x3F; /* We use the bits 0-5 for address */
	  eMBInit(MB_RTU,u8Address,0,115200,MB_PAR_NONE); /* And 115k2 for serial speed */
	  eMBEnable(); /* We enable the Stack */
	  NVIC_ClearPendingIRQ(USIC0_0_IRQn); /* We clear any pending ire for ter uart */
	  NVIC_EnableIRQ(USIC0_0_IRQn); /* And enable it's interrupts */
	  while(1 == 1)
	  {
		/* Infinite loop */
		  if(Delay>0){
			  Delay--;
		  }else{
			  XMC_GPIO_ToggleOutput(XMC_GPIO_PORT0,4);
			  Delay=0xFFFF;
		  }
		  mb_stack_task(); /* Serve the Stack *7
	  }
	}
}
void Default_handler( void ){
/* We shall never end here */
}

void USIC0_0_IRQHandler ( void ){
/* This is the IRQ Handler for the USCI ( USART in the Atmel World ) */


/* This can be called by diffetent Sources therfore we need to determine witch */
uint32_t status = XMC_UART_CH_GetStatusFlag( XMC_UART0_CH0 );

    // Did we receive data?
    if ((status & (XMC_UART_CH_STATUS_FLAG_ALTERNATIVE_RECEIVE_INDICATION | XMC_UART_CH_STATUS_FLAG_RECEIVE_INDICATION)) != 0U)
    {
    	/* We need to add the correct callback here */
    	MB_RxHandler();
    	XMC_UART_CH_ClearStatusFlag(XMC_UART0_CH0, XMC_UART_CH_STATUS_FLAG_ALTERNATIVE_RECEIVE_INDICATION );
    	XMC_UART_CH_ClearStatusFlag(XMC_UART0_CH0, XMC_UART_CH_STATUS_FLAG_RECEIVE_INDICATION);
    }

    /* Transmission in Progress ? */
    if (( status & ( XMC_UART_CH_STATUS_FLAG_TRANSMIT_BUFFER_INDICATION)) != 0U){
    	/* We can if requiered refill data to the buffer */
    	 XMC_UART_CH_ClearStatusFlag(XMC_UART0_CH0, XMC_UART_CH_STATUS_FLAG_TRANSMIT_BUFFER_INDICATION);

    }

    /* Transmitt finished */
    if ((status & ( XMC_UART_CH_STATUS_FLAG_TRANSMIT_SHIFT_INDICATION)) != 0U){
    	/* We can if requiered refill data to the buffer */
    	XMC_UART_CH_ClearStatusFlag(XMC_UART0_CH0, XMC_UART_CH_STATUS_FLAG_TRANSMIT_SHIFT_INDICATION);
    	MB_TxHandler();
    }

	if ((status & ( XMC_UART_CH_STATUS_FLAG_TRANSMITTER_FRAME_FINISHED)) != 0U){
	    	/* We can if requiered refill data to the buffer */
	    	XMC_UART_CH_ClearStatusFlag(XMC_UART0_CH0, XMC_UART_CH_STATUS_FLAG_TRANSMITTER_FRAME_FINISHED);

	}

}

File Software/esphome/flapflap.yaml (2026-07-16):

esphome:
  name: flapflap-stunde
  on_boot:
    priority: -100
    then:
      - delay: 1s
      - lambda: |-
          id(tlv_test).set_pages((int) id(pages_number).state);
          id(tlv_test).set_zero_angle(id(zero_angle_number).state);
          id(tlv_test).set_calibration_leaf((int) id(calibration_leaf_number).state);
          id(tlv_test).set_target_leaf((int) id(target_leaf_number).state);
          id(tlv_test).set_mode("Stunden");

external_components:
  - source:
      type: local
      path: my_components

esp32:
  board: esp32-c3-devkitm-1
  framework:
    type: arduino

logger:
  level: DEBUG

api:
  encryption:
    key: "VgD8k05glNhFwXwStnMPbjwfET4pIDJ3TDBhezexu5A="

ota:
  - platform: esphome
    password: "1b5f8b66616918112e6f7647a8effe6e"

wifi:
  ssid: !secret wifi_ssid
  password: !secret wifi_password
  output_power: 8.5dB

time:
  - platform: sntp
    id: internet_time
    timezone: Europe/Berlin

i2c:
  sda: GPIO0
  scl: GPIO1
  scan: true
  frequency: 100kHz

binary_sensor:
  - platform: gpio
    id: flap_button
    name: "FlapFlap Taster"
    pin:
      number: GPIO10
      mode:
        input: true
        pullup: true
      inverted: true
    filters:
      - delayed_on: 20ms
      - delayed_off: 20ms
    on_press:
      then:
        - lambda: |-
            id(tlv_test).pulse_once();

button:
  - platform: restart
    name: "FlapFlap Neustart"

  - platform: template
    name: "FlapFlap Hier kalibrieren"
    on_press:
      then:
        - lambda: |-
            id(tlv_test).calibrate_here();
            auto call = id(zero_angle_number).make_call();
            call.set_value(id(tlv_test).get_zero_angle());
            call.perform();

  - platform: template
    name: "FlapFlap Sensor neu initialisieren"
    on_press:
      then:
        - lambda: |-
            id(tlv_test).reinitialize_sensor();

  - platform: template
    name: "FlapFlap Einzelpuls"
    on_press:
      then:
        - lambda: |-
            id(tlv_test).pulse_once();

  - platform: template
    name: "FlapFlap Ein Blatt weiter"
    on_press:
      then:
        - lambda: |-
            id(tlv_test).advance_one_leaf();

  - platform: template
    name: "FlapFlap Zu Zielblatt fahren"
    on_press:
      then:
        - lambda: |-
            id(tlv_test).start_move_to_target();

  - platform: template
    name: "FlapFlap Stop"
    on_press:
      then:
        - lambda: |-
            id(tlv_test).stop_move();

number:
  - platform: template
    name: "FlapFlap Nullwinkel"
    id: zero_angle_number
    min_value: 0
    max_value: 359.9
    step: 0.1
    optimistic: true
    restore_value: true
    initial_value: 0.0
    set_action:
      - lambda: |-
          id(tlv_test).set_zero_angle(x);

  - platform: template
    name: "FlapFlap Kalibrierblatt"
    id: calibration_leaf_number
    min_value: 0
    max_value: 61
    step: 1
    optimistic: true
    restore_value: true
    initial_value: 0
    set_action:
      - lambda: |-
          id(tlv_test).set_calibration_leaf((int) x);

  - platform: template
    name: "FlapFlap Zielblatt"
    id: target_leaf_number
    min_value: 0
    max_value: 61
    step: 1
    optimistic: true
    restore_value: true
    initial_value: 0
    set_action:
      - lambda: |-
          id(tlv_test).set_target_leaf((int) x);

  - platform: template
    name: "FlapFlap Blattanzahl"
    id: pages_number
    min_value: 1
    max_value: 100
    step: 1
    optimistic: true
    restore_value: true
    initial_value: 62
    set_action:
      - lambda: |-
          id(tlv_test).set_pages((int) x);

select:
  - platform: template
    name: "FlapFlap Modus"
    id: mode_select
    optimistic: true
    restore_value: false
    options:
      - Sekunden
      - Minuten
      - Stunden
      - Leerblatt
      - Kalibrierung
      - Manuell
    initial_option: Stunden
    set_action:
      - lambda: |-
          id(tlv_test).set_mode(x);

tlv493d_test:
  id: tlv_test
  update_interval: 20ms
  zero_angle: 0.0
  calibration_leaf: 0
  target_leaf: 0
  pages: 62
  mode: "Stunden"
  sensor_samples: 8
  motor_pin: GPIO3
  motor_pulse_ms: 30
  motor_settle_ms: 35
  move_timeout_ms: 15000
  max_pulses_per_move: 120
  unchanged_limit: 8
  move_stop_lead: 0.35
  seconds_stop_lead: 0.12
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

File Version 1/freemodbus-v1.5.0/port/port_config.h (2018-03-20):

/******************************************************************************
* Software License Agreement
*
* Copyright (c) 2016, Infineon Technologies AG
* All rights reserved.
*
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
* Neither the name of the copyright holders nor the names of its contributors
* may be used to endorse or promote products derived from this software
* without specific prior written permission

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
* To improve the quality of the software, users are encouraged to share
* modifications, enhancements or bug fixes with Infineon Technologies AG
* (dave@infineon.com).
*
*****************************************************************************/
/**
* @file port_config.h
* @date 11 May,2016
* @version 1.0.0
*
* @brief Port layer defines and API function prototype definitions
*
* History
*
* 11 May 2016 Version 1.0
* Initial revision
*/

#ifndef PORT_CONFIG_H_
#define PORT_CONFIG_H_

#ifdef __cplusplus
PR_BEGIN_EXTERN_C
#endif
/****************************************************************
* MACROS AND DEFINES
***************************************************************/

/*! \defgroup modbus_cfg Modbus Configuration
 *
 * Most modules in the protocol stack are completly optional and can be
 * excluded. This is specially important if target resources are very small
 * and program memory space should be saved.<br>
 *
 * All of these settings are available in the file <code>mbconfig.h</code>
 */
/*! \addtogroup modbus_cfg
 *  @{
 */
/*! \brief If Modbus ASCII support is enabled. */
#define MB_ASCII_ENABLED                        (  1U )

/*! \brief If Modbus RTU support is enabled. */
#define MB_RTU_ENABLED                          (  1U )

/*! \brief If Modbus TCP support is enabled. */
#define MB_TCP_ENABLED                          (  0U )

/*! \brief Port used if Modbus TCP support is enabled. */
#define MB_TCP_DEFAULT_PORT                     ( 502U ) /* TCP listening port. */

/*! \brief The character timeout value for Modbus ASCII.
 *
 * The character timeout value is not fixed for Modbus ASCII and is therefore
 * a configuration option. It should be set to the maximum expected delay
 * time of the network.
 */
#define MB_ASCII_TIMEOUT_SEC                    (  1U )

/*! \brief Timeout to wait in ASCII prior to enabling transmitter.
 *
 * If defined the function calls vMBPortSerialDelay with the argument
 * MB_ASCII_TIMEOUT_WAIT_BEFORE_SEND_MS to allow for a delay before
 * the serial transmitter is enabled. This is required because some
 * targets are so fast that there is no time between receiving and
 * transmitting the frame. If the master is to slow with enabling its
 * receiver then he will not receive the response correctly.
 */
#ifndef MB_ASCII_TIMEOUT_WAIT_BEFORE_SEND_MS
#define MB_ASCII_TIMEOUT_WAIT_BEFORE_SEND_MS    ( 0U )
#endif

/*! \brief Maximum number of Modbus functions codes the protocol stack
 *    should support.
 *
 * The maximum number of supported Modbus functions must be greater than
 * the sum of all enabled functions in this file and custom function
 * handlers. If set to small adding more functions will fail.
 */
#define MB_FUNC_HANDLERS_MAX                    ( 16U )

/*! \brief Number of bytes which should be allocated for the <em>Report Slave ID
 *    </em>command.
 *
 * This number limits the maximum size of the additional segment in the
 * report slave id function. See eMBSetSlaveID(  ) for more information on
 * how to set this value. It is only used if MB_FUNC_OTHER_REP_SLAVEID_ENABLED
 * is set to <code>1</code>.
 */
#define MB_FUNC_OTHER_REP_SLAVEID_BUF           ( 32U )

/*! \brief If the <em>Report Slave ID</em> function should be enabled. */
#define MB_FUNC_OTHER_REP_SLAVEID_ENABLED       (  1U )

/*! \brief If the <em>Read Input Registers</em> function should be enabled. */
#define MB_FUNC_READ_INPUT_ENABLED              (  1U )

/*! \brief If the <em>Read Holding Registers</em> function should be enabled. */
#define MB_FUNC_READ_HOLDING_ENABLED            (  1U )

/*! \brief If the <em>Write Single Register</em> function should be enabled. */
#define MB_FUNC_WRITE_HOLDING_ENABLED           (  1U )

/*! \brief If the <em>Write Multiple registers</em> function should be enabled. */
#define MB_FUNC_WRITE_MULTIPLE_HOLDING_ENABLED  (  1U )

/*! \brief If the <em>Read Coils</em> function should be enabled. */
#define MB_FUNC_READ_COILS_ENABLED              (  1U )

/*! \brief If the <em>Write Coils</em> function should be enabled. */
#define MB_FUNC_WRITE_COIL_ENABLED              (  1U )

/*! \brief If the <em>Write Multiple Coils</em> function should be enabled. */
#define MB_FUNC_WRITE_MULTIPLE_COILS_ENABLED    (  1U )

/*! \brief If the <em>Read Discrete Inputs</em> function should be enabled. */
#define MB_FUNC_READ_DISCRETE_INPUTS_ENABLED    (  1U )

/*! \brief If the <em>Read/Write Multiple Registers</em> function should be enabled. */
#define MB_FUNC_READWRITE_HOLDING_ENABLED       (  1U )

/*! @} */
#ifdef __cplusplus
    PR_END_EXTERN_C
#endif
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

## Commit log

2018-03-20 Initial commit
    Erste Version
    [memory.ods]
2024-09-28 Sortiert in neuen Ordner
    Weg frei für die neue Version!
    [memory.ods]
2024-10-02 CAD update
    jetzt sogar mit den richtigen Löchern und etwas größeren Löchern, damit man die M3 Schrauben sogar anschrauben kann!!
    [inkrementalgeber_unterseite.stp]
2024-10-02 Update Stream 1.10.24
    Non-Working version!
    Update im Stream, mit Winkelnullkalibrierung, Stufeneinteilung und noch Fehlern
2024-10-02 updated comment
    Wichtiges Kommentar zur Erklärung des Codes vergessen!
2024-10-03 stream 2.10.24
    - added config.json support for destination-step and for zero-point calibration
    - flapflap until destination reached
    - some changes to sensor value aquisition
2024-10-09 Anpassungen an PCB
    Öffnung vergrößert, damit man jetzt auch eine Platine in das Gehäuse schrauben kann. Davor war es ja für Jumeprwires ausgelegt
2024-10-09 added pulsonix backup
    Ordner 001-Pulsonix ist für Backups da, der muss jetzt ned unbedingt ins Git...
2024-10-09 Initial commit
    erste, noch nichtmal ansatzweise fertige Version der Platine
    [flapflap_rPi_picoW.sch]
2024-10-09 angepasst an die platine die rein kommt.
    jetzt mit anschlag für die platine, damit der sensor perfekt liegt
2024-10-09 finale
    platine fertig geroutet, ganz schön viel angepasst. RPi auf die Unterseite, RTC und so mit auf einen I2C, pins ausgeblendet vom rpi etc
    [flapflap_rPi_picoW.sch]
2024-10-09 initial commit
    ganz viele CAD-Daten wegen Step-Datei von der Platine
    [flapflap_rpi_picow.3mf]
2024-10-09 Initial commit
    Fertigungsdaten für die Platine als Gerber und in Zip
    [flapflap_rPi_picoW(Bottom).gbr, flapflap_rPi_picoW(Drill Drawing).gbr, flapflap_rPi_picoW(Paste Mask Bottom).gbr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]
2024-10-10 optimierung
    fase an der bohrung weggelassen, macht nur probleme beim 3d-druck und ich habe eh keine passenden senkkopfschrauben hier...
2024-10-10 small changes
    nur stp neu exportiert und 3d druckdaten aktualisiert
    [flapflap_rpi_picow.3mf, inkrementalgeber_oberseite.stp]
2024-10-10 Anpassungen light
    Step ohne Fase und am Rand die Ausnehmung wieder hinzu, wurde unabsichtlich wegoptimiert
    [inkrementalgeber_oberseite.stp]
2024-10-16 Stream 15.10.24
    Aktualisierte Version vom Stream. Wir fragen jetzt die Zeit ab und wandeln Sommer/Winterzeit um. Kleine Änderungen nach dem Stream: Hauptschleife optimiert für mehr Stabilität
2024-10-16 step aktualisiert
    step datei mit den neuen cad-daten exportiert
    [inkrementalgeber_unterseite.stp]
2024-10-16 optimierung
    kleine optimierungen damit der code besser läuft für den nächsten stream
2024-10-23 Minor changes
    Kleine Anpassungen bei der Nullpunktkalibrierung... Ersten Wert verwerfen und dann Average von 10 nehmen zwecks Genauigkeit und so
2024-10-23 Streamupdate
    Diesmal mit richtig rum gepolten Triac, aber noch nicht fertitsch....
    [flapflap_rPi_picoW.sch]
2024-10-24 Platinenupdate
    Fehler ausgebessert, Widerstand vergrößert (2W) für Triac-Ansteuerung. Triac jetzt richtig belegt. Wenn es immer noch nicht geht: Chat ist Schuld!
    [flapflap_rPi_picoW.sch]
2024-11-08 initial commit
    schnelles gehäuse 3d-gedruckt, damit die 230V verstaut sind und sich nur wenige leute damit umbringen können.
    [stromversorgung_deckel.stp, stromversorgung_unterteil.stp]
2024-11-11 Minor changes
    Ein paar Kleinigkeiten ausgebessert, die ChatGPT verbockt hat
2026-07-16 Initial commit
    Neue Platine, neues alles.
    [bom.csv, designators.csv, flapflap.kicad_pcb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]
